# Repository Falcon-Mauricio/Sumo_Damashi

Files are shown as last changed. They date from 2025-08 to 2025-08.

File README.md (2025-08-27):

# Sumo DAMASHI

**Damashi** es un robot de sumo autónomo diseñado para competir en la disciplina de **<a href="https://lnr-argentina.com.ar/reglamentos/Reglamento%20Sumo.pdf" target="_blank">Sumo autónomo</a>** organizada por la **<a href="https://lnr-argentina.com.ar/" target="_blank">LNR</a>**.  

<div align="center">
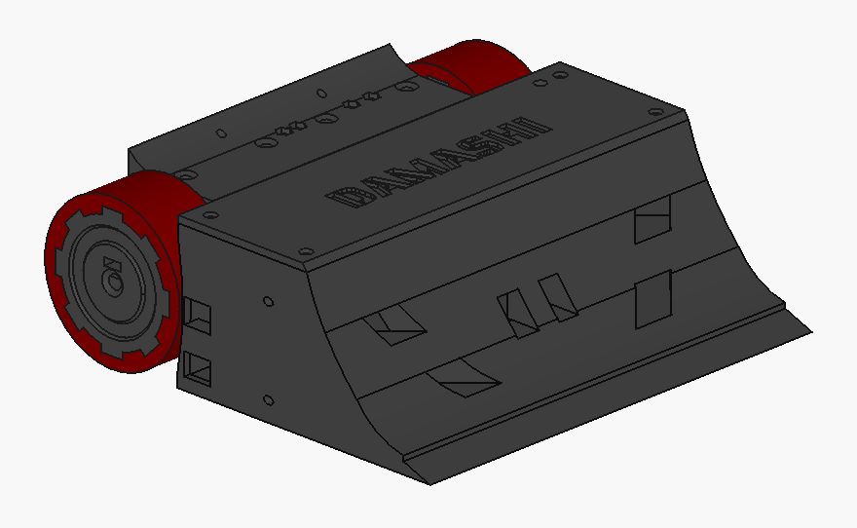
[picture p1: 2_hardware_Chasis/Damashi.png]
Vista_Damashi
  
</div>

---

## 🚀 Características principales

| Especificación | Detalle |
|---|---|
| **Dimensiones** | 190x190x65 mm |
| **Peso** | ≤ 2500 g |
| **Chasis** | Impreso en 3D |
| **Batería** | LiPo 4S |
| **Microcontrolador** | ESP32 DevKit V1 |
| **Sensores** | 3 x QRE1113GR (tatami) + 5 x SHARP GP2Y0A02YK0F de distancia (laterales y frontales) |
| **Motores** | APYS SP6 - 260 RPM |
| **Driver de motores** | BTS7960 |

---

## ⚡ Entradas / Salidas (I/O)

<table>
<tr>

<td>

### Entradas (sensores y botones)

| Pin ESP32 | Descripción |
|---|---|
| GPIO34 | SHARP_LEFT |
| GPIO35 | SHARP_RIGHT |
| GPIO32 | SHARP_MID_LEFT |
| GPIO33 | SHARP_MID |
| GPIO25 | SHARP_MID_RIGHT |
| GPIO26 | TATAMI_B (sensor tatami trasero) |
| GPIO27 | TATAMI_L (sensor tatami izquierdo) |
| GPIO13 | TATAMI_R (sensor tatami derecho) |
| GPIO17 | PUSH_2 |
| GPIO18 | PUSH_1 |

</td>

<td>

### Salidas (motores y otros)

| Pin ESP32 | Descripción |
|---|---|
| GPIO23 | M2B |
| GPIO22 | M2A |
| GPIO19 | M1A |
| GPIO21 | M1B |
| GPIO18 | BUZZER |
| GPIO05 | LED_1 |

</td>

</tr>
</table>

---

## 🛠 Tecnologías utilizadas

- **FreeCAD** → Diseño de piezas 3D (soporte de motores, chasis y demas piezas auxiliares)  
- **KiCad** → Diseño del PCB  
- **PlatformIO (VSCode)** → Firmware en ESP32 (C++ / Arduino framework)  

---

## 📂 Archivos

- `1_hardware_pcb/` → Archivos de KiCad (PCB + esquemas)  
- `2_hardware_chasis/` → Archivos Free

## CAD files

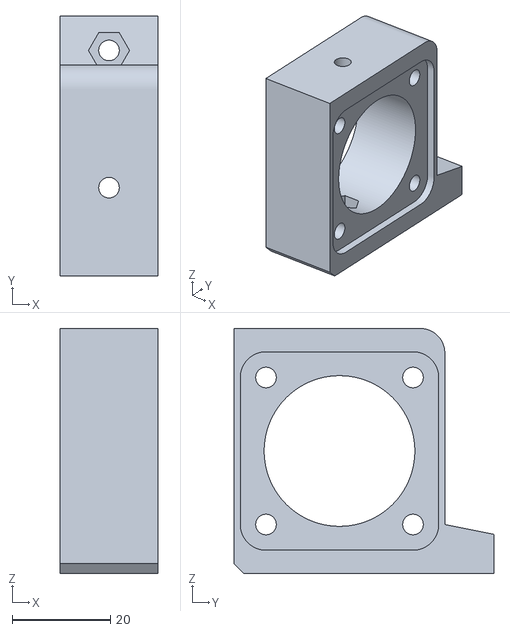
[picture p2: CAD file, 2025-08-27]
2_hardware_Chasis/STL_File/Braquet_MotorD.stl
20.0 x 53.0 x 50.0

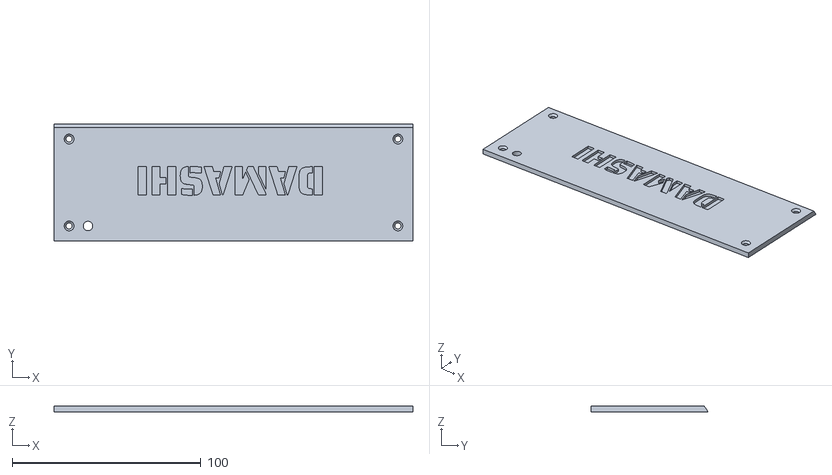
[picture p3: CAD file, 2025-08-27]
2_hardware_Chasis/STL_File/Tapa.stl
190.0 x 62.0 x 3.00

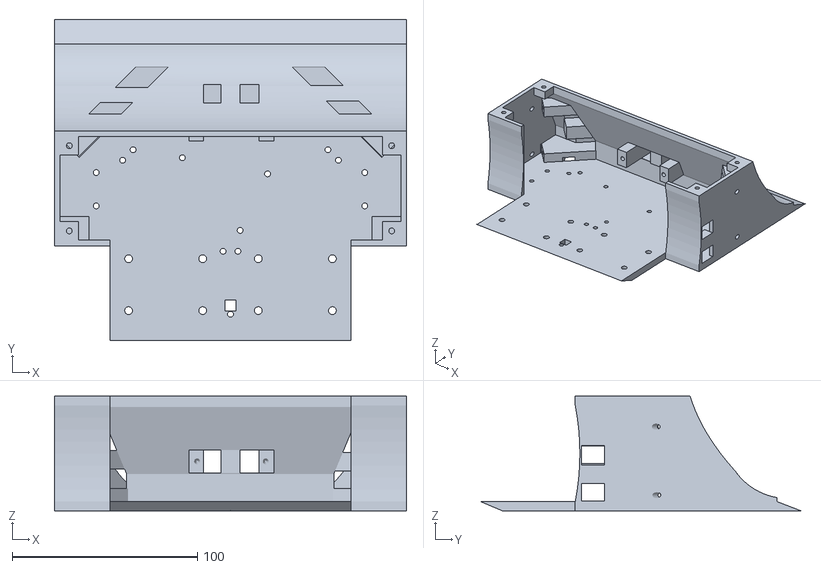
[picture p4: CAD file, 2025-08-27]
2_hardware_Chasis/STL_File/Chasis.stl
190.0 x 173.0 x 62.0

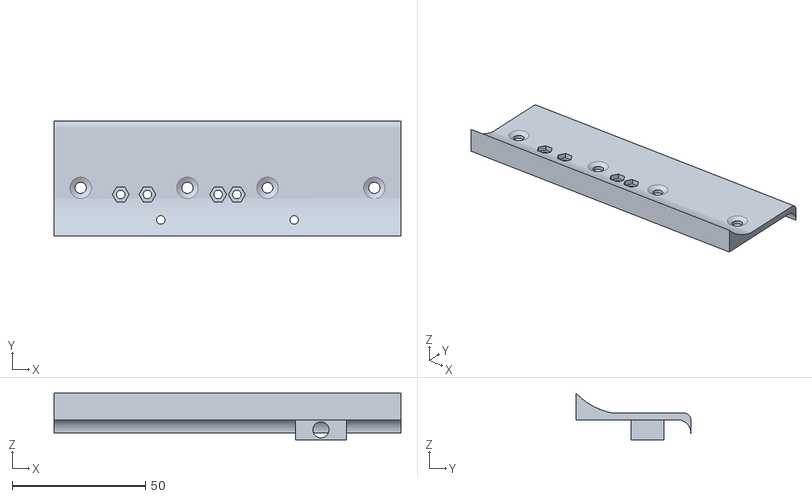
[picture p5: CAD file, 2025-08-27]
2_hardware_Chasis/STL_File/Soporte_Logica_Plomo.stl
130.0 x 43.0 x 17.5

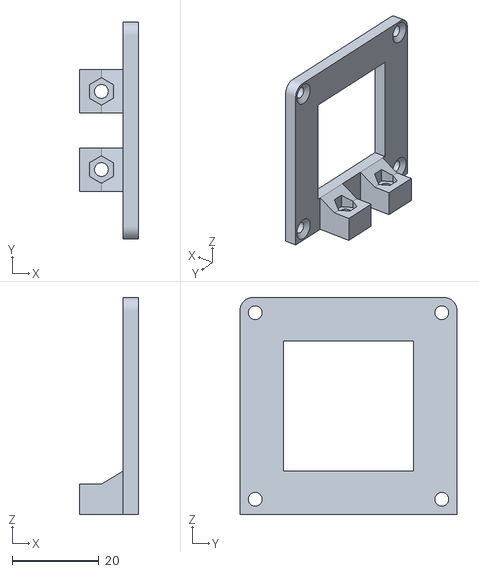
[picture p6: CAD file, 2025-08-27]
2_hardware_Chasis/STL_File/Soporte_BTS.stl
13.5 x 50.0 x 50.0

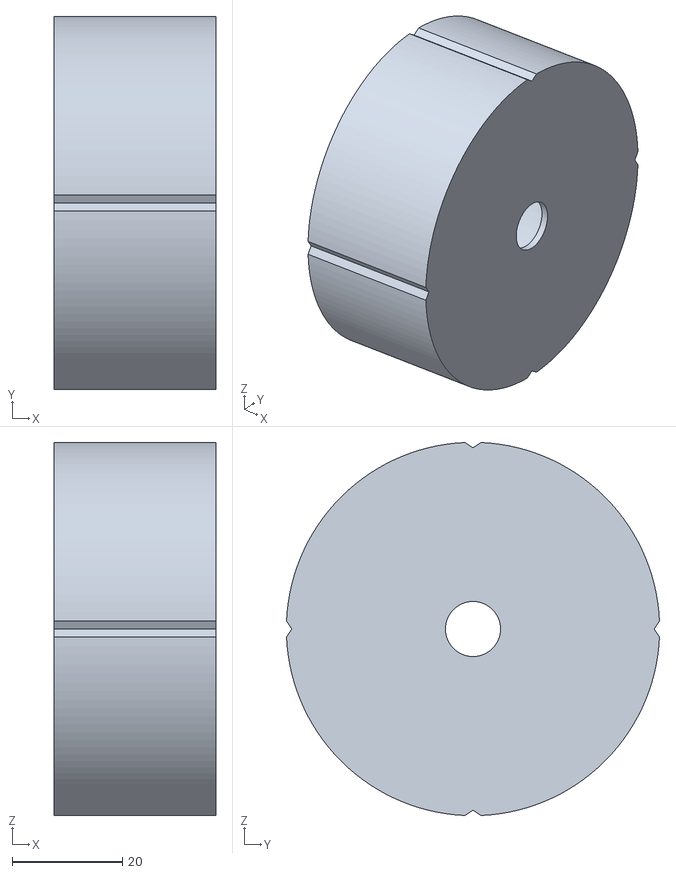
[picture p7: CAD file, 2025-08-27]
2_hardware_Chasis/STL_File/Molde.stl
29.4 x 67.7 x 67.7

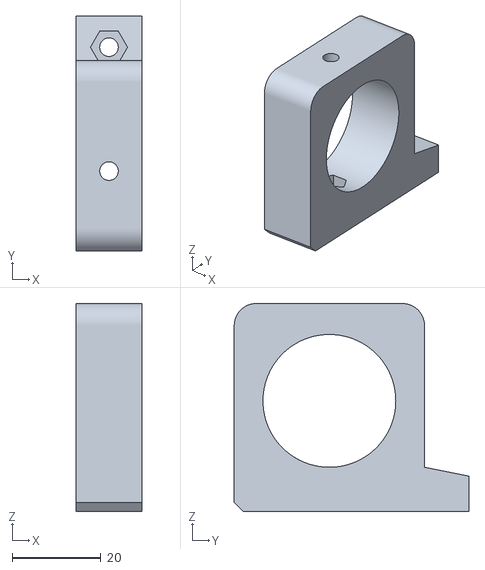
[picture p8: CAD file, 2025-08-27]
2_hardware_Chasis/STL_File/Abrazadera_Motor.stl
15.0 x 53.0 x 47.0

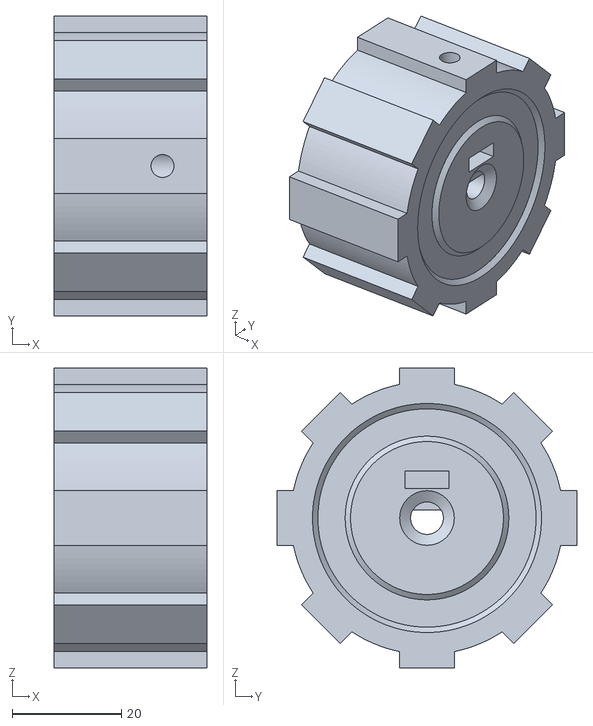
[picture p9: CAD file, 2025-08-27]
2_hardware_Chasis/STL_File/Llanta.stl
28.0 x 55.0 x 55.0

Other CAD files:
2_hardware_Chasis/STL_File/Braquet_MotorI.stl

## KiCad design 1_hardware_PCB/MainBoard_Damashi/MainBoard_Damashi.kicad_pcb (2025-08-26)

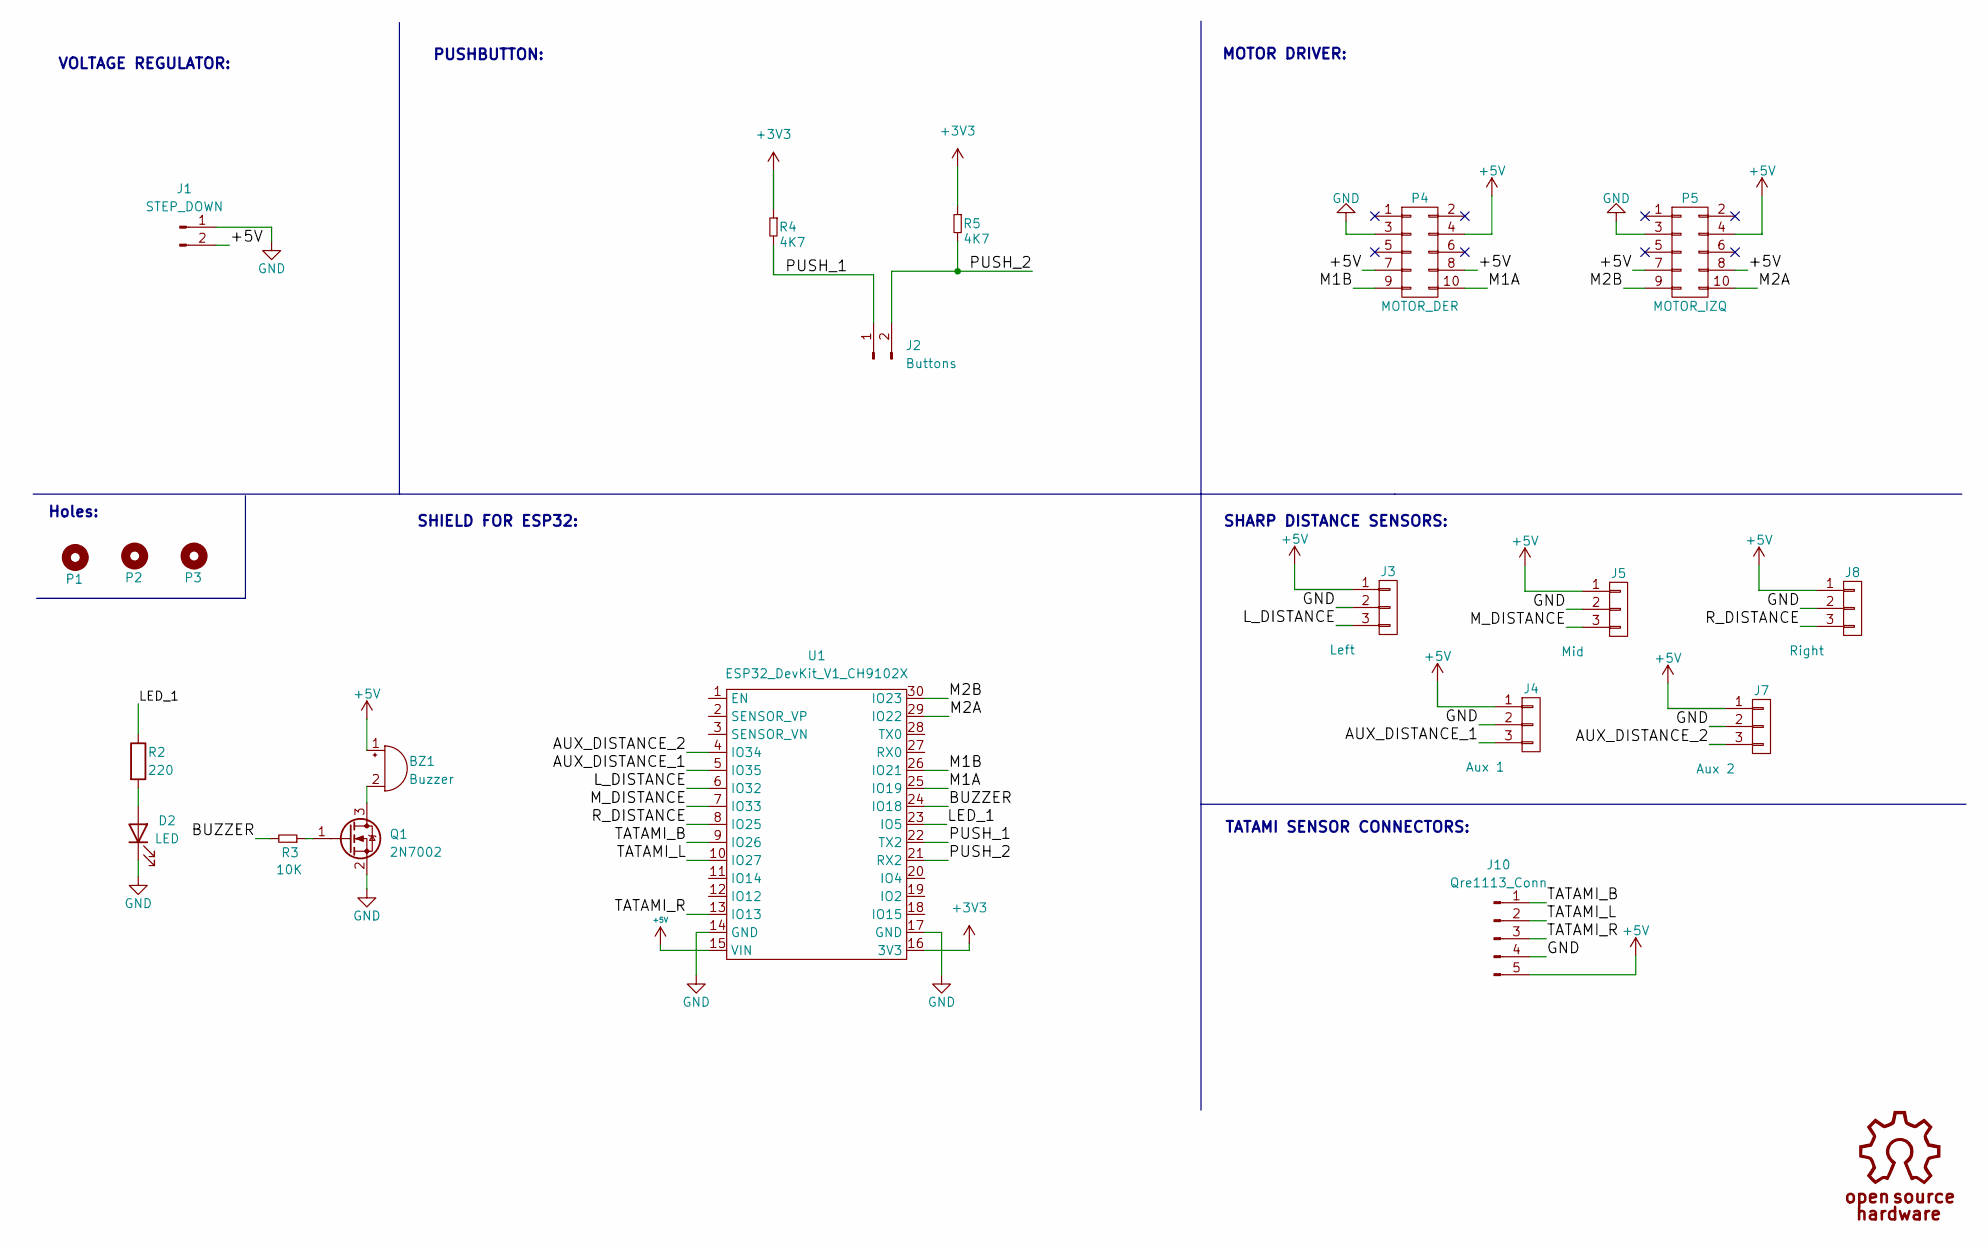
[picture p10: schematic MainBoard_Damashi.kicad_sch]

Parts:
BZ1: Buzzer; Buzzer_12mm
D2: LED; PinHeader_1x02_P2.54mm_Horizontal
J1: STEP_DOWN; PinHeader_1x02_P2.54mm_Horizontal
J2: Buttons; PinHeader_1x02_P2.54mm_Horizontal
J3: Left; FanPinHeader_1x03_P2.54mm_Vertical
J4: Aux 1; FanPinHeader_1x03_P2.54mm_Vertical
J5: Mid; FanPinHeader_1x03_P2.54mm_Vertical
J7: Aux 2; FanPinHeader_1x03_P2.54mm_Vertical
J8: Right; FanPinHeader_1x03_P2.54mm_Vertical
J10: Qre1113_Conn; PinHeader_1x05_P2.54mm_Horizontal
P1, P2, P3: Mounting_Hole; Separador_M3_5mm
P4: MOTOR_DER; Header_2x05x2.54mm_Vertical
P5: MOTOR_IZQ; Header_2x05x2.54mm_Vertical
Q1: 2N7002; SOT-23
R2: 220; R_1206
R3: 10K; R_1206
R4, R5: 4K7; R_1206
U1: ESP32_DevKit_V1_CH9102X

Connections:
+3V3: R4.1, R5.1, U1.16 (3V3)
+5V: BZ1.1 (-), J1.2, J3.1, J4.1, J5.1, J7.1, J8.1, J10.5, P4.4, P4.7, P4.8, P5.4, P5.7, P5.8, U1.15 (VIN)
/AUX_DISTANCE_1: J4.3, U1.5 (IO35)
/AUX_DISTANCE_2: J7.3, U1.4 (IO34)
/BUZZER: R3.2, U1.24 (IO18)
/LED_1: R2.1, U1.23 (IO5)
/L_DISTANCE: J3.3, U1.6 (IO32)
/M1A: P4.10, U1.25 (IO19)
/M1B: P4.9, U1.26 (IO21)
/M2A: P5.10, U1.29 (IO22)
/M2B: P5.9, U1.30 (IO23)
/M_DISTANCE: J5.3, U1.7 (IO33)
/PUSH_1: J2.1, R4.2, U1.22 (TX2)
/PUSH_2: J2.2, R5.2, U1.21 (RX2)
/R_DISTANCE: J8.3, U1.8 (IO25)
/TATAMI_B: J10.1, U1.9 (IO26)
/TATAMI_L: J10.2, U1.10 (IO27)
/TATAMI_R: J10.3, U1.13 (IO13)
GND: D2.1 (K), J1.1, J3.2, J4.2, J5.2, J7.2, J8.2, J10.4, P4.3, P5.3, Q1.2 (S), U1.14 (GND), U1.17 (GND)
unnamed: BZ1.2 (+), Q1.3 (D)
unnamed: D2.2 (A), R2.2
unnamed: Q1.1 (G), R3.1

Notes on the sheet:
TATAMI SENSOR CONNECTORS:
SHARP DISTANCE SENSORS:
MOTOR DRIVER:
VOLTAGE REGULATOR:
Holes:
PUSHBUTTON:
SHIELD FOR ESP32:

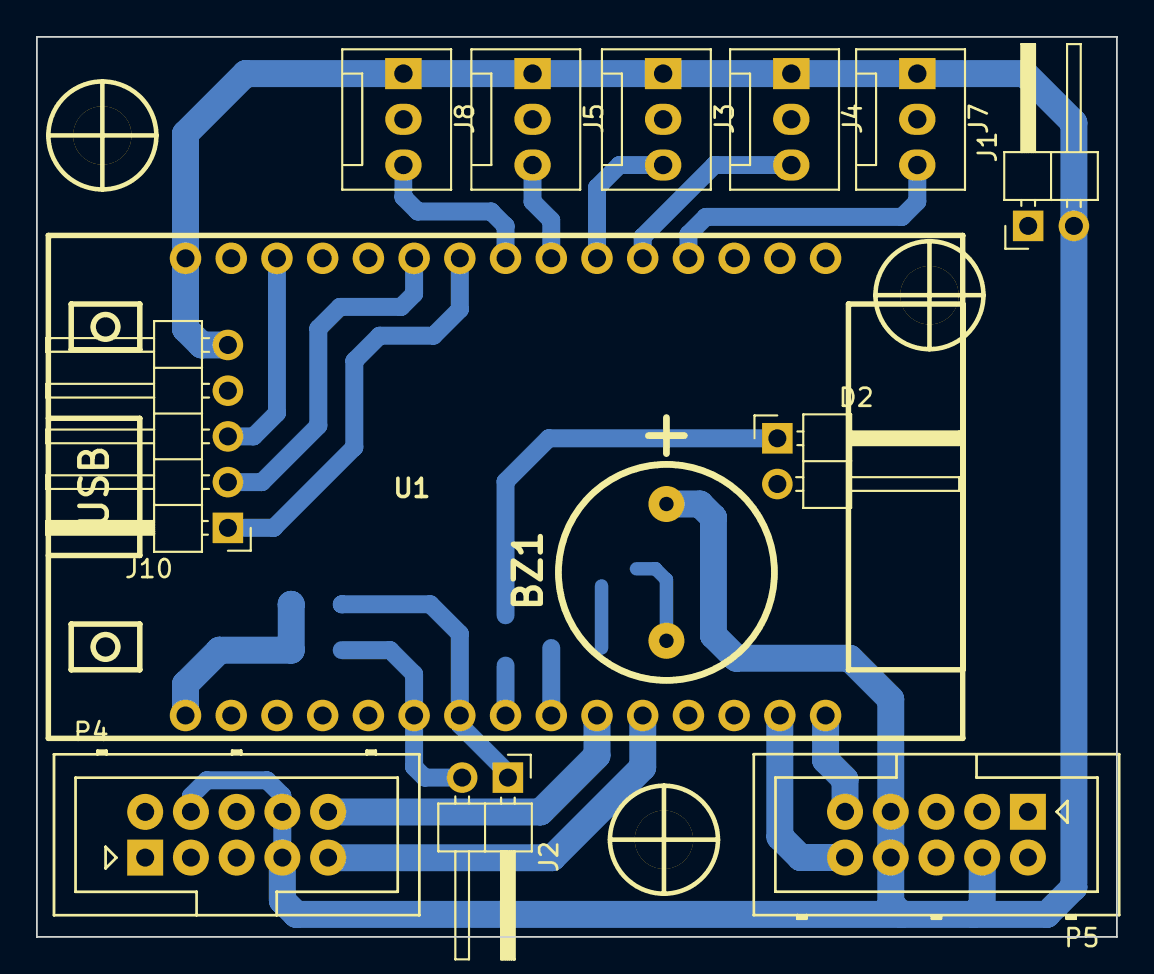
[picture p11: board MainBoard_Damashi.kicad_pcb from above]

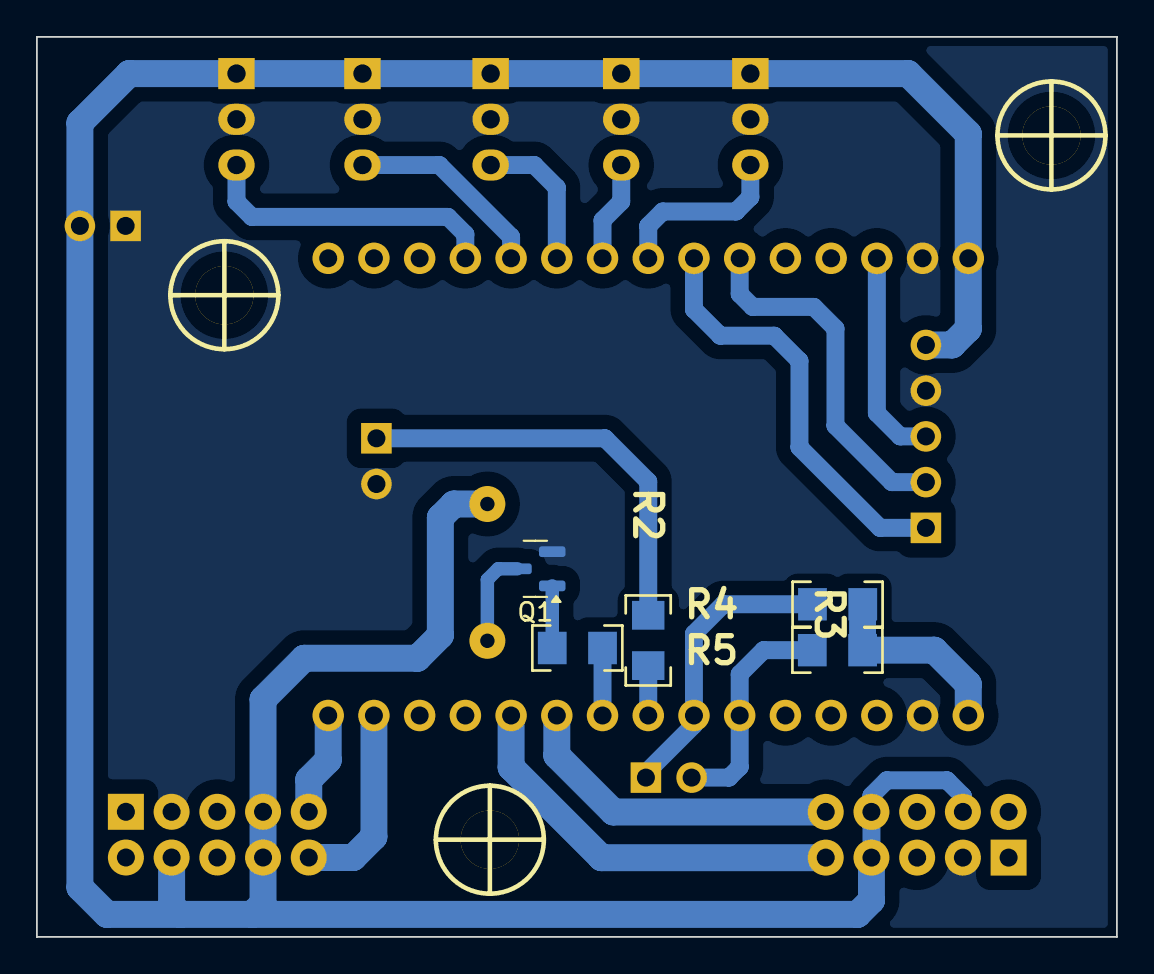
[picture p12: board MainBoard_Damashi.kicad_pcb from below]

Board: 2 copper layers, 60.0 x 50.0 mm, 21 parts (5 on the bottom side), 22 nets.

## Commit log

2025-08-25 Diseñe el SCH
    [MainBoard_Damashi.kicad_pcb, MainBoard_Damashi.kicad_sch]
2025-08-26 Diseñe el PCB
    [MainBoard_Damashi.kicad_pcb, MainBoard_Damashi.kicad_sch]
2025-08-27 Diseñe el Chasis
    [Chasis-Part.stl]
2025-08-27 Terminado el modelado 3D por completo
    [Abrazadera_Motor.stl, Braquet_MotorD.stl, Braquet_MotorI.stl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]
